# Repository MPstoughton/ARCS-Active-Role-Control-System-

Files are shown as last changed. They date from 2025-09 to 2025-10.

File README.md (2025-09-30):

# ARCS-Active-Rocket-Control-System-

Precision in flight stability is a fundamental requirement for high-powered rocketry, directly influencing both mission safety and performance outcomes. Roll instability, in particular, can degrade aerodynamic efficiency, increase structural loading, and induce trajectory dispersions that compromise recovery reliability and payload success. Slender body rockets can be more inclined to experience unpredicted trajectories due to high roll rates. 

In the context of university and amateur rocketry programs, including the Intercollegiate Rocket Engineering Competition (IREC), NASA Student Launch Initiative (SLI), and the Friends of Amateur Rocketry OUT (FAR-OUT) competition, teams must address stability challenges while operating under strict limitations of weight, cost, and manufacturability. Competition-class rockets typically have masses between 20-40 kg, operate with peak dynamic pressures of 8–15 kPa, and are constrained to commercially available manufacturing processes. Within these regimes, any solution for roll stabilization must provide sufficient control authority while adding less than 1–2 percent to system mass and maintaining costs below approximately $500.

Conventional passive stabilization techniques, such as canted fins, generate roll torque through induced aerodynamic asymmetry but result in drag penalties that reduce apogee depending on Mach number and cant angle. Advanced active approaches, including thrust vector control, cold-gas thrusters, and reaction wheels, offer greater precision but impose significant penalties in mass, power, and cost. Consequently, there remains a clear technical gap for a lightweight, modular, and reliable roll control system tailored to the needs of competition-class rocketry.

The Active Rocket Control System (ARCS) project is conceived to address this gap by introducing an aerodynamic fin-based actuation mechanism capable of dynamically correcting roll during supersonic flight. The system integrates aerodynamic control surfaces with embedded actuation and onboard sensing, enabling closed-loop control of roll rates while minimizing drag penalties. The design emphasizes modularity, allowing integration into existing vehicles with minimal airframe modification, while maintaining manufacturability with student-accessible processes. Beyond roll control, the framework can be expanded to multi-axis stabilization, thereby serving as an enabling technology for advanced trajectory shaping, payload protection, and recovery optimization in future university-level aerospace programs.

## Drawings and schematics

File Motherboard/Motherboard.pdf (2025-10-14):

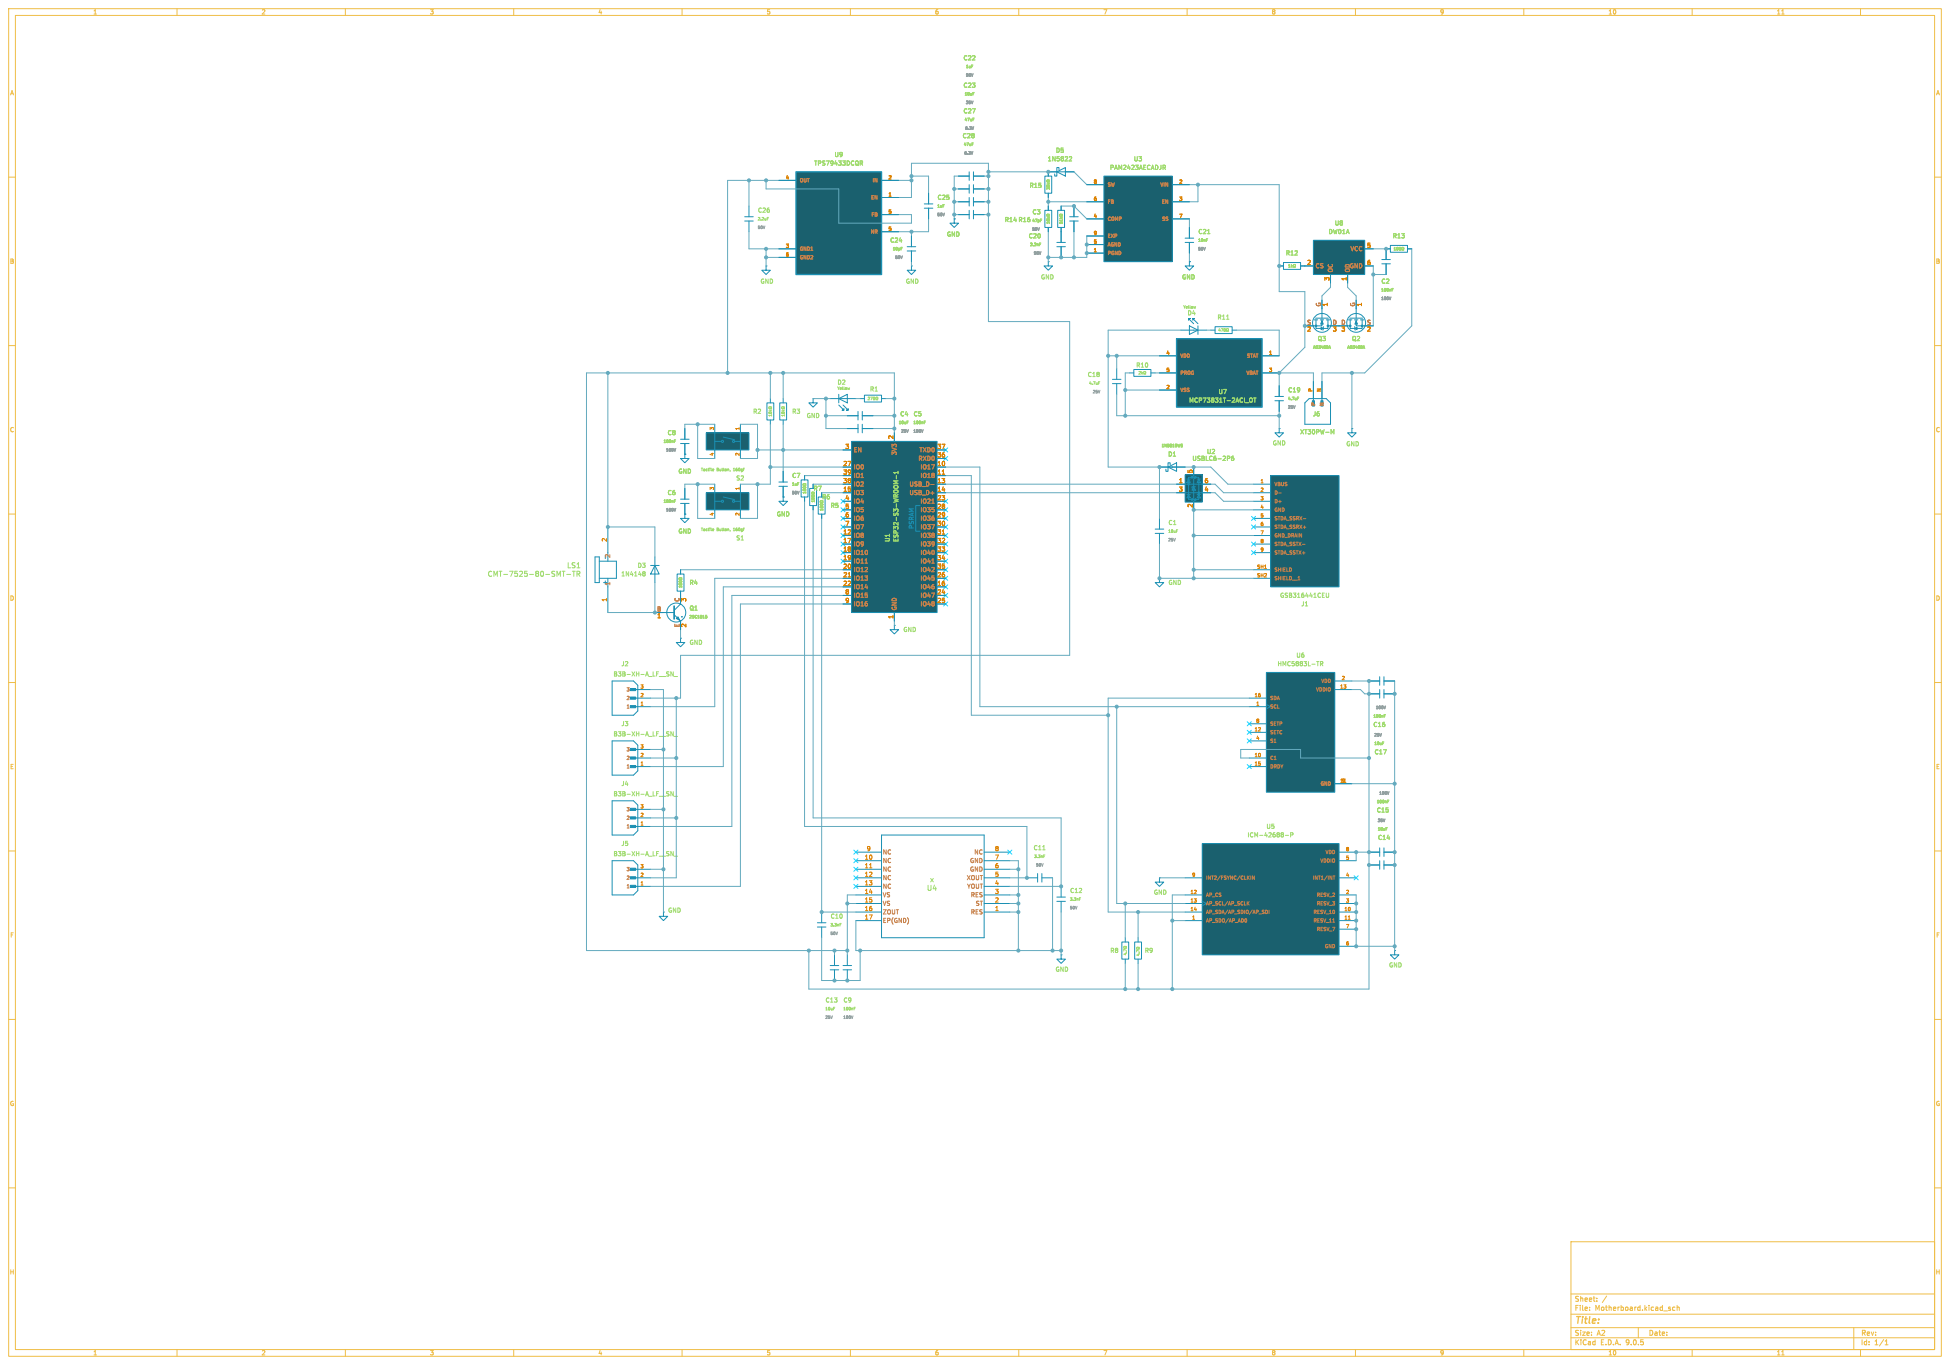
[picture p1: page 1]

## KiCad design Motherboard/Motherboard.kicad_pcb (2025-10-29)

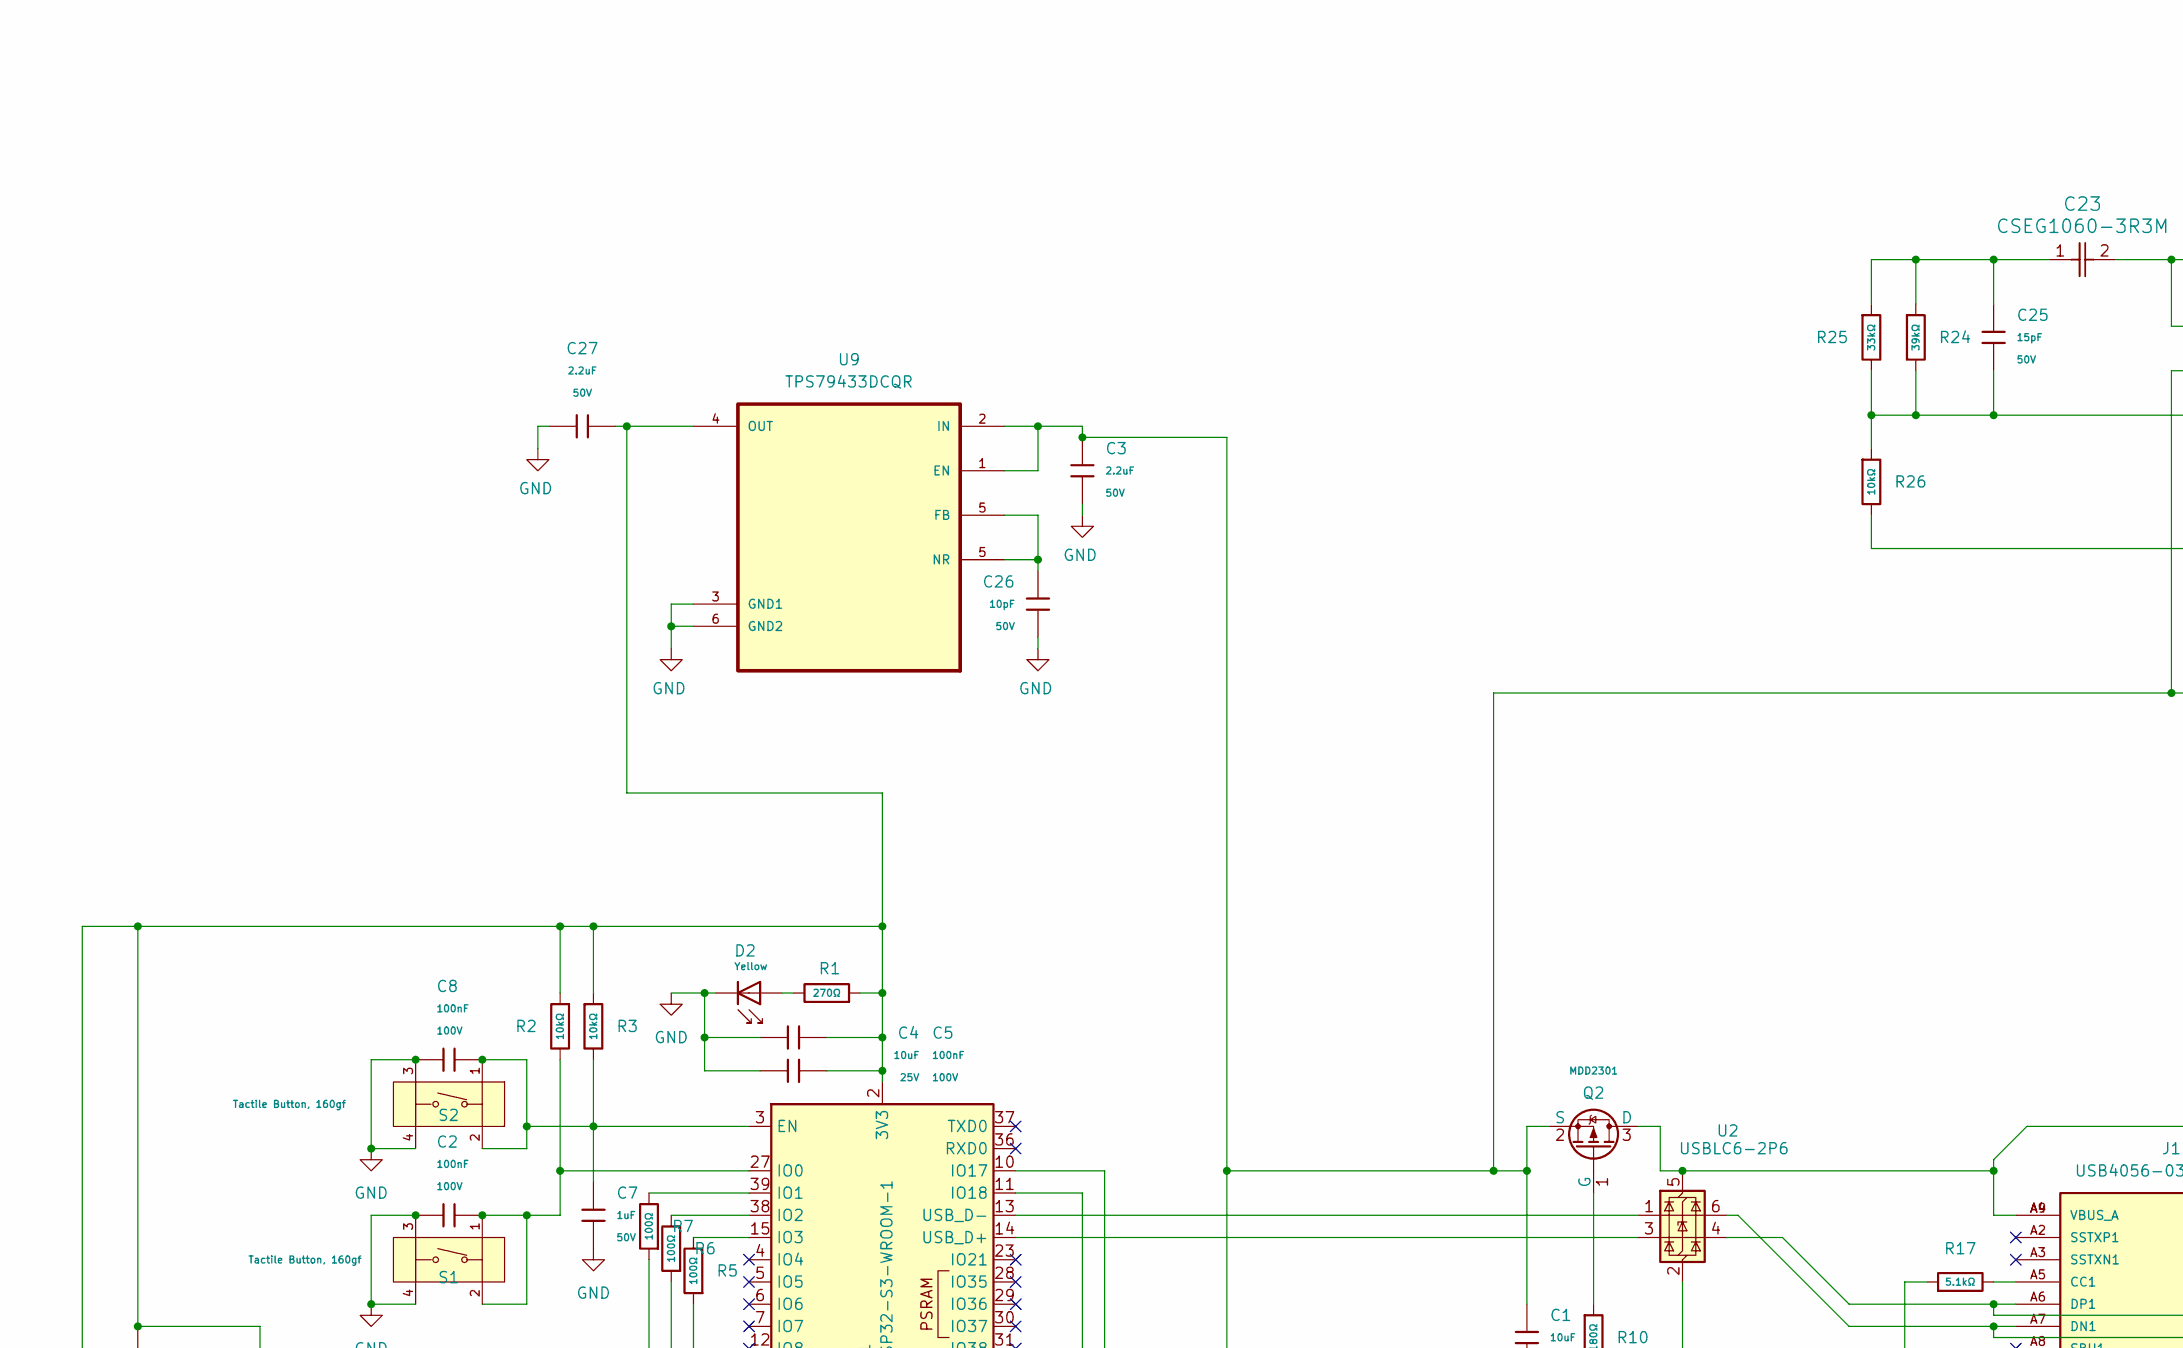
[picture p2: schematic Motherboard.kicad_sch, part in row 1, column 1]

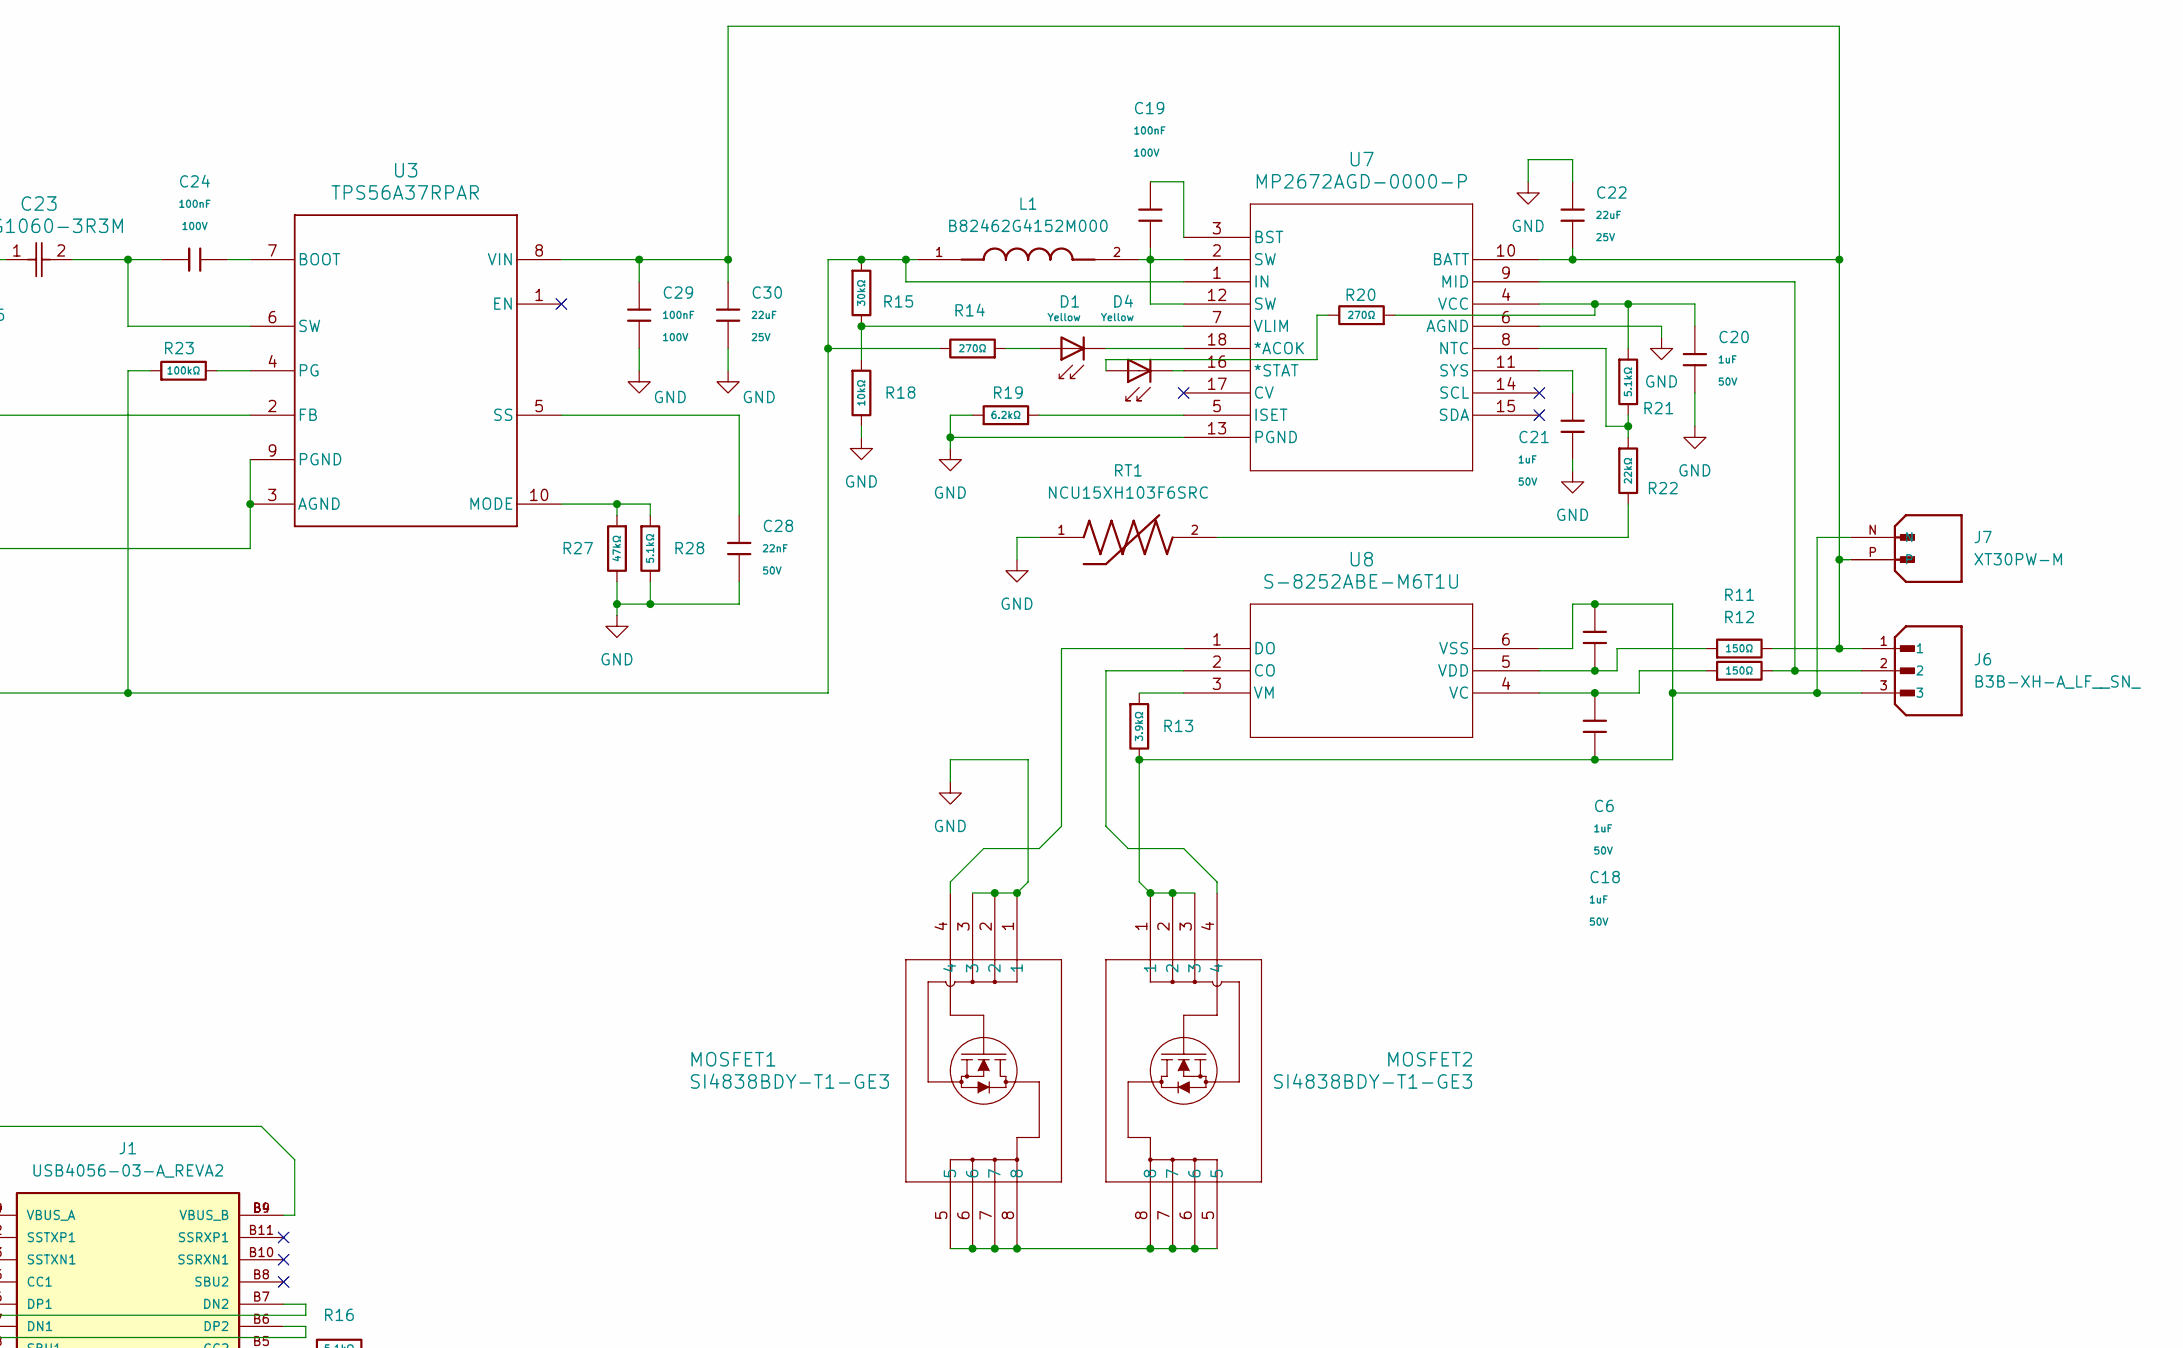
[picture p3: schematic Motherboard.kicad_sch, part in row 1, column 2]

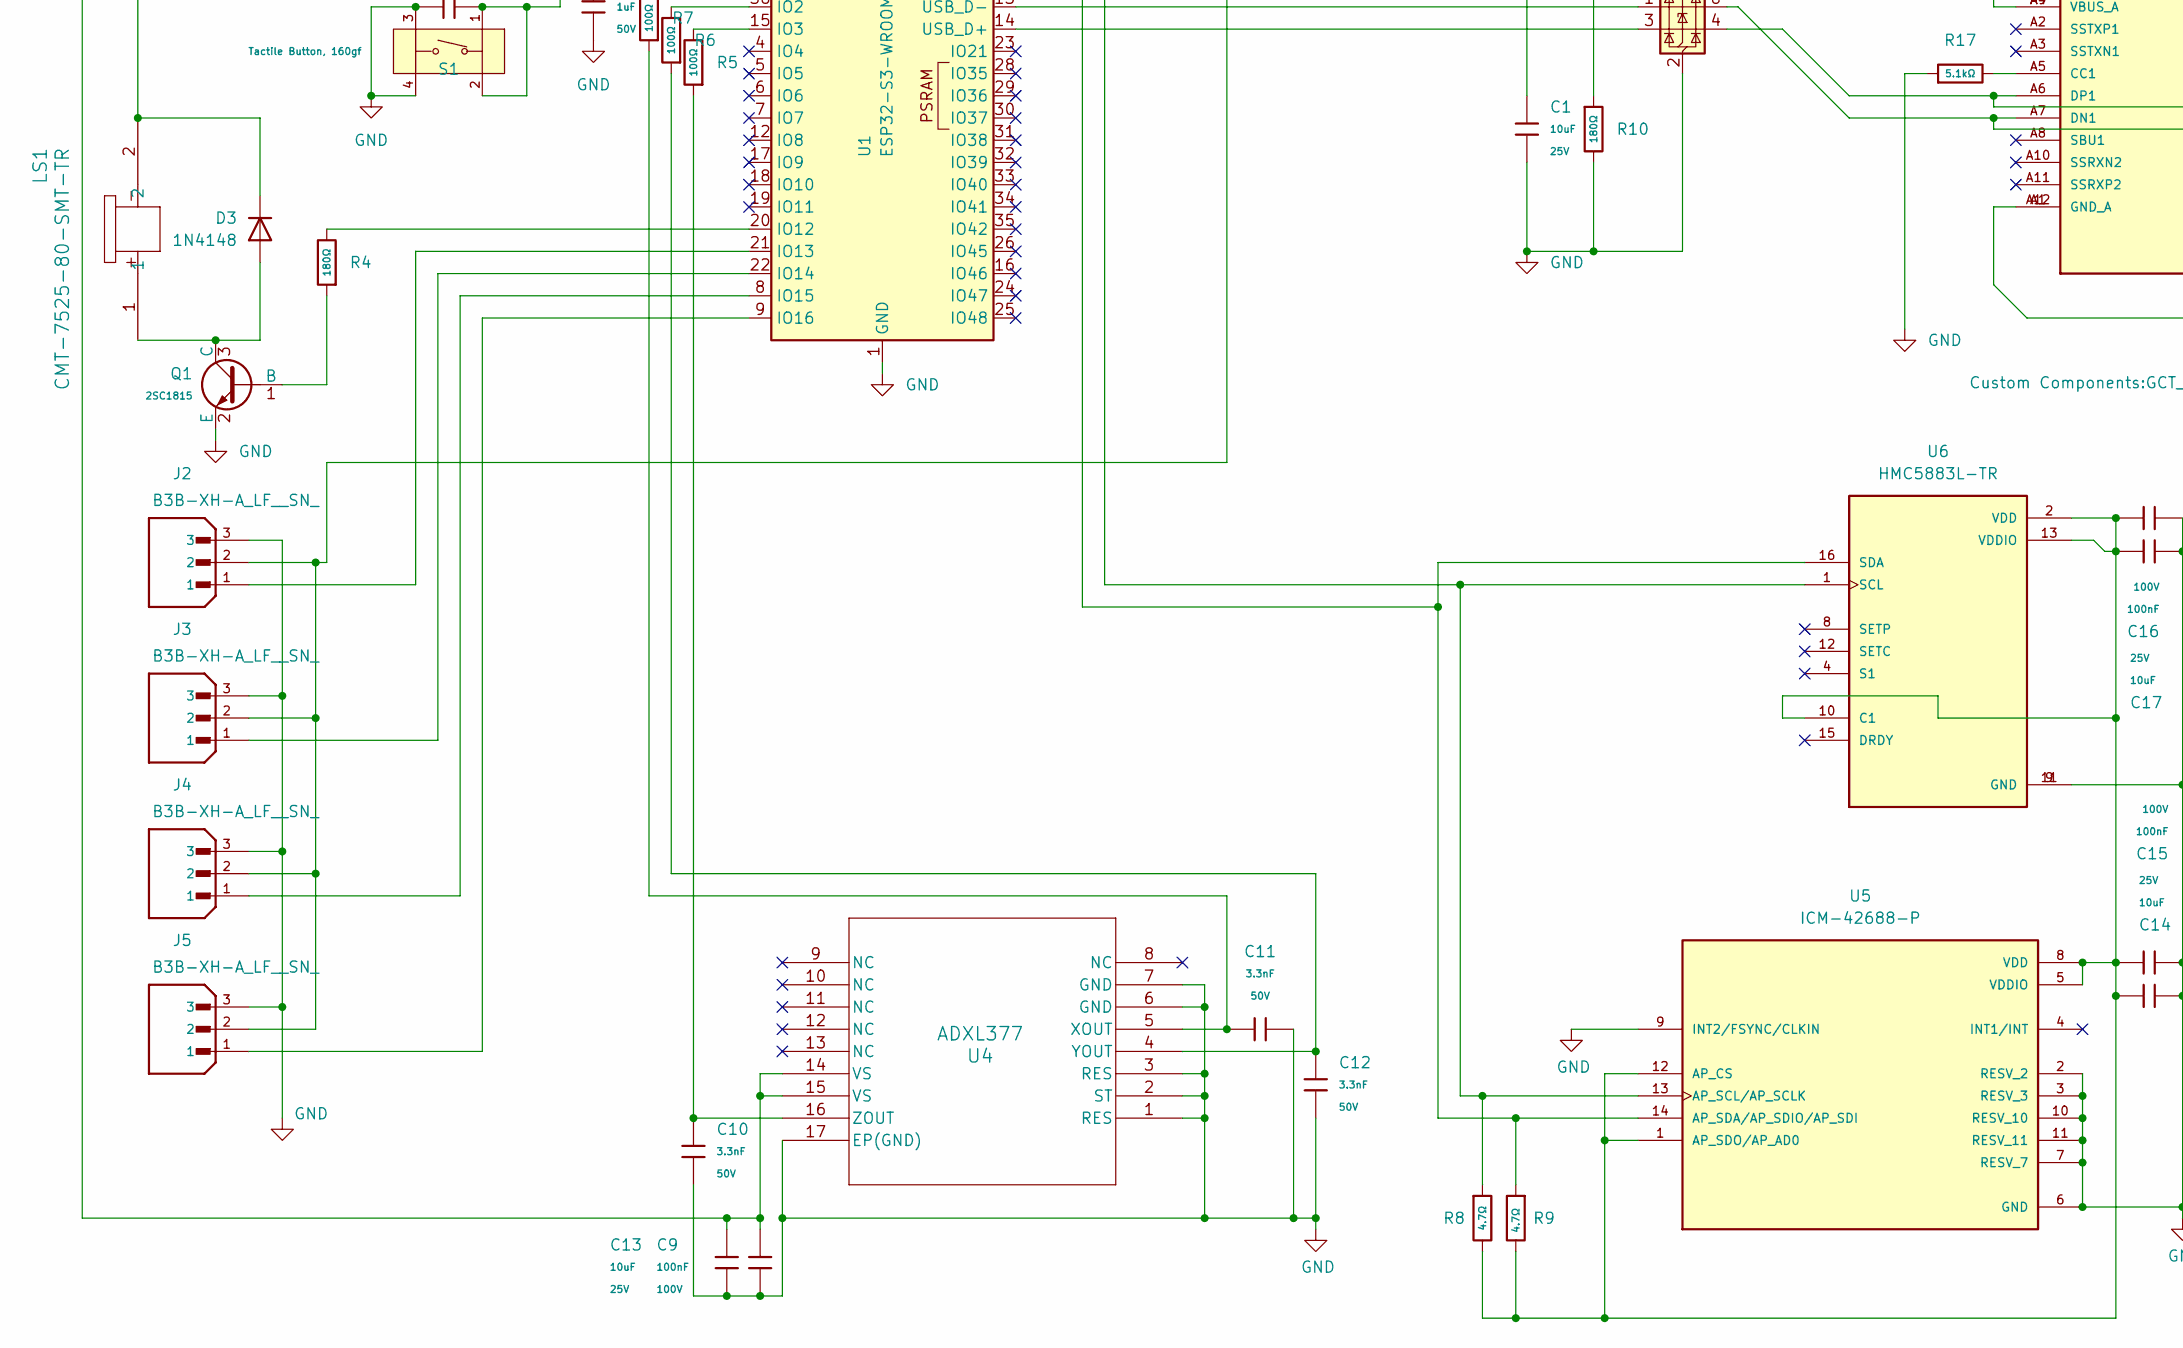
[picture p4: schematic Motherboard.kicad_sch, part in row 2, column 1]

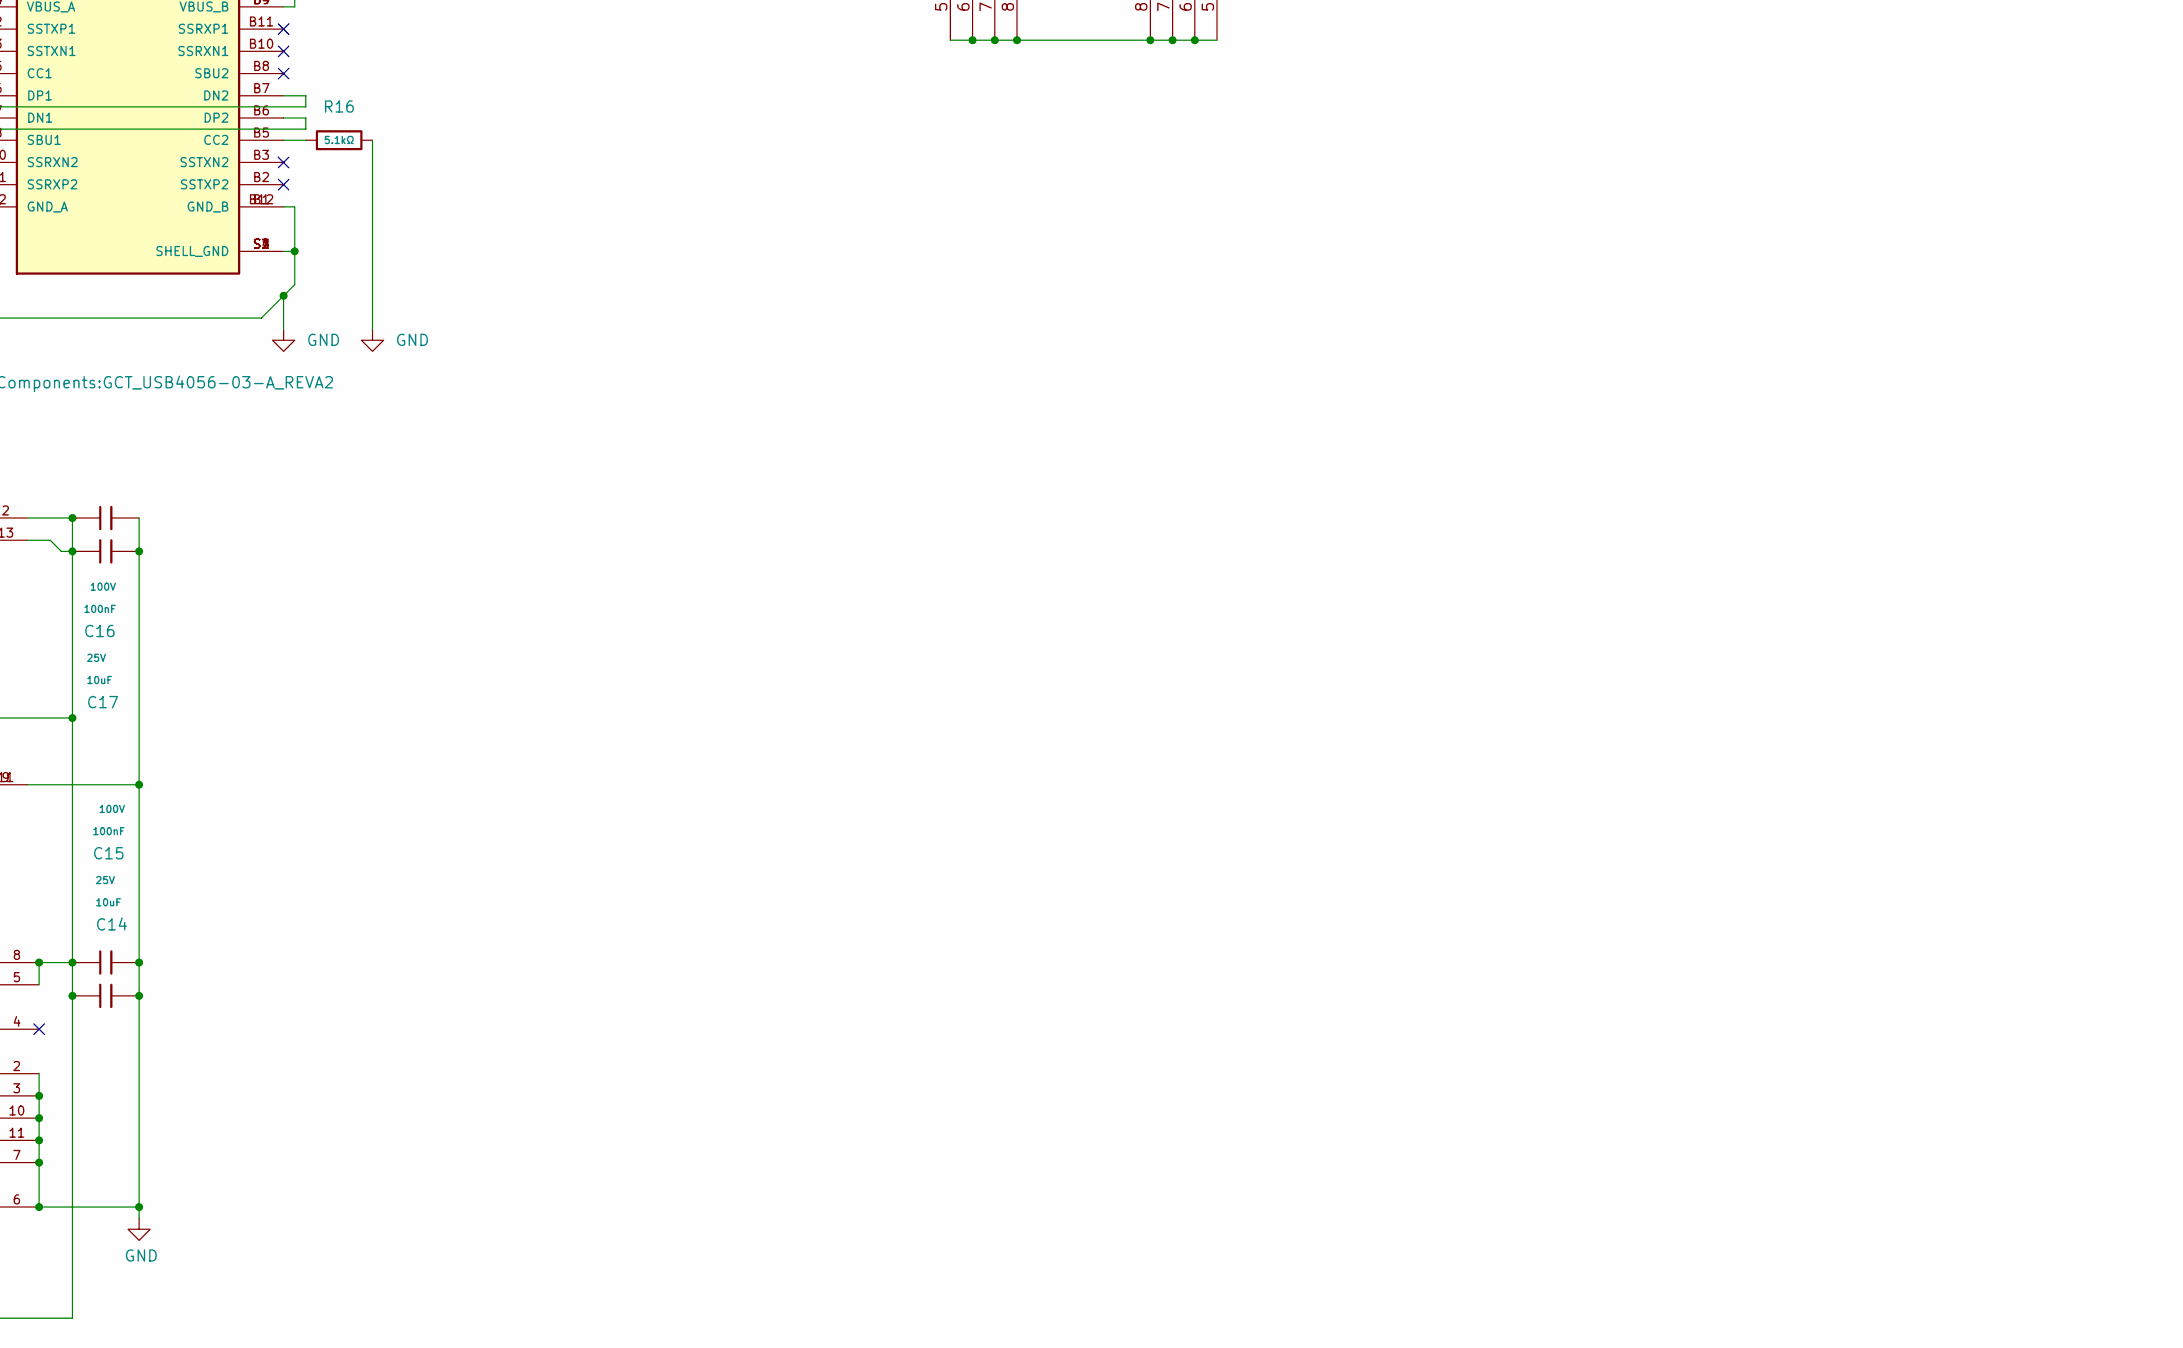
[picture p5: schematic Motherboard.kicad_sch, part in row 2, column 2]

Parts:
C1, C4, C13, C14, C17: 10uF; C_0805; Voltage Rated 25V; Tolerance ±10%; Part CL21A106KAYNNNE; LCSC C15850
C2, C5, C8, C9, C15, C16, C19, C24, C29: 100nF; C_0805; Voltage Rated 100V; Tolerance ±10%; Part CL21B104KCFNNNE; LCSC C28233
C3, C27: 2.2uF; C_0805; Voltage Rated 50V; Tolerance ±10%; Part CL21A225KBQNNNE; LCSC C377773
C6, C7, C18, C20, C21: 1uF; C_0805; Voltage Rated 50V; Tolerance ±10%; Part CL21B105KBFNNNE; LCSC C28323
C10, C11, C12: 3.3nF; C_0603; Voltage Rated 50V; Tolerance ±10%; Part CL10B332KB8NNNC; LCSC C1613
C22, C30: 22uF; C_0805; Voltage Rated 25V; Tolerance ±20%; Part CL21A226MAQNNNE; LCSC C45783
C23: CSEG1060-3R3M; CAP_CSEG1060-3R3M_COD
C25: 15pF; C_0805; Voltage Rated 50V; Tolerance ±5%; Part CC0805JRNPO9BN150; LCSC C107110
C26: 10pF; C_0603; Voltage Rated 50V; Tolerance ±5%; Part CL10C100JB8NNNC; LCSC C1634
C28: 22nF; C_0805; Voltage Rated 50V; Tolerance ±10%; Part CL21B223KBANNNC; LCSC C1729
D1, D2, D4: Yellow; D_0805; Part KT-0805Y; LCSC C2296
D3: 1N4148; D_DO-35_SOD27_P7.62mm_Horizontal
J1: USB4056-03-A_REVA2; GCT_USB4056-03-A_REVA2; PARTREV A2; DigiKey_Part_Number 2073-USB4056-03-ACT-ND
J2, J3, J4, J5, J6: B3B-XH-A_LF__SN_; JST_B3B-XH-A_LF__SN_; PARTREV 7/4/21
J7: XT30PW-M; AMASS_XT30PW-M; PARTREV 1.2
L1: B82462G4152M000; IND_B82462G4152M000; PARTREV 2018-10
LS1: CMT-7525-80-SMT-TR; CMT-7525-80-SMT-TR_CUD
MOSFET1, MOSFET2: SI4838BDY-T1-GE3; SOIC8_NARROW_VIS
Q1: 2SC1815; Q_SOT-23; Part 2SC1815; LCSC C20069143
Q2: MDD2301; Q_SOT-23; Part MDD2301; LCSC C427391
R1, R14, R20: 270Ω; R_0805; Overload Voltage (Max) 150V; Tolerance ±1%; Part 0805W8F2700T5E; LCSC C17590
R2, R3, R26: 10kΩ; R_0805; Overload Voltage (Max) 150V; Tolerance ±1%; Part 0805W8F1002T5E; LCSC C17414
R4, R10: 180Ω; R_0805; Overload Voltage (Max) 150V; Tolerance ±1%; Part 0805W8F1800T5E; LCSC C25270
R5, R6, R7: 100Ω; R_0603; Overload Voltage (Max) 75V; Tolerance ±1%; Part 0603WAF1000T5E; LCSC C22775
R8, R9: 4.7Ω; R_0805; Overload Voltage (Max) 150V; Tolerance ±1%; Part 0805W8F470KT5E; LCSC C17675
R11, R12: 150Ω; R_0805; Overload Voltage (Max) 150V; Tolerance ±1%; Part 0805W8F1500T5E; LCSC C17471
R13: 3.9kΩ; R_0805; Overload Voltage (Max) 150V; Tolerance ±1%; Part 0805W8F3901T5E; LCSC C17614
R15: 30kΩ; R_0805; Overload Voltage (Max) 150V; Tolerance ±1%; Part 0805W8F3002T5E; LCSC C17621
R16, R17, R21, R28: 5.1kΩ; R_0805; Overload Voltage (Max) 150V; Tolerance ±1%; Part 0805W8F5101T5E; LCSC C27834
R18: 10kΩ; R_0603; Overload Voltage (Max) 75V; Tolerance ±1%; Part 0603WAF1002T5E; LCSC C25804
R19: 6.2kΩ; R_0805; Overload Voltage (Max) 150V; Tolerance ±1%; Part 0805W8F6201T5E; LCSC C17767
R22: 22kΩ; R_0805; Overload Voltage (Max) 150V; Tolerance ±1%; Part 0805W8F2202T5E; LCSC C17560
R23: 100kΩ; R_0805; Overload Voltage (Max) 150V; Tolerance ±1%; Part 0805W8F1003T5E; LCSC C149504
R24: 39kΩ; R_0805; Overload Voltage (Max) 150V; Tolerance ±1%; Part 0805W8F3902T5E; LCSC C25826
R25: 33kΩ; R_0805; Overload Voltage (Max) 150V; Tolerance ±1%; Part 0805W8F3302T5E; LCSC C17633
R27: 47kΩ; R_0805; Overload Voltage (Max) 150V; Tolerance ±1%; Part 0805W8F4702T5E; LCSC C17713
RT1: NCU15XH103F6SRC; THRMC1005X55N
S1, S2: Tactile Button, 160gf; SW-SMD_4P-L5.1-W5.1-P3.70-LS6.5-TL-2; Voltage Rating (Dc) 12V; Part TS-1187A-B-A-B; LCSC C318884
U1: ESP32-S3-WROOM-1
U2: USBLC6-2P6; SOT-666
U3: TPS56A37RPAR; RPA0010A-MFG
U4: ADXL377; CP_16_28_ADI
U5: ICM-42688-P; PQFN50P300X250X97-14N; PARTREV 1.2
U6: HMC5883L-TR; XDCR_HMC5883L-TR; PARTREV E
U7: MP2672AGD-0000-P; QFN-18_MP2672A_MNP
U8: S-8252ABE-M6T1U; SOT236-A-PKG_MP006-A-P-SD-2.1_ABL
U9: TPS79433DCQR; SOT127P706X180-6N; DigiKey_Part_Number 296-14437-1-ND

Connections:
GND: C1.2, C2.2, C3.1, C4.2, C5.2, C7.2, C8.2, C9.2, C10.1, C11.2, C12.1, C13.1, C14.1, C15.2, C16.2, C17.1, C20.2, C21.2, C22.1, C26.2, C27.1, C28.2, C29.2, C30.2, D2.1, J1.A1 (GND_A), J1.A12 (GND_A), J1.B1 (GND_B), J1.B12 (GND_B), J1.S1 (SHELL_GND), J1.S2 (SHELL_GND), J1.S3 (SHELL_GND), J1.S4 (SHELL_GND), J2.3, J3.3, J4.3, J5.3, MOSFET1.1, MOSFET1.2, MOSFET1.3, Q1.2 (E), R10.2, R16.2, R17.1, R18.2, R19.1, R27.2, R28.2, RT1.1, S1.3 (C), S1.4 (D), S2.3 (C), S2.4 (D), U1.1 (GND), U1.40 (GND), U1.41 (GND), U2.2 (GND), U4.1 (RES), U4.2 (ST), U4.3 (RES), U4.6 (GND), U4.7 (GND), U4.17 (EP(GND)), U5.2 (RESV_2), U5.3 (RESV_3), U5.6 (GND), U5.7 (RESV_7), U5.9 (INT2/FSYNC/CLKIN), U5.10 (RESV_10), U5.11 (RESV_11), U6.9 (GND), U6.11 (GND), U7.6 (AGND), U7.13 (PGND), U9.3 (GND1), U9.6 (GND2)
unnamed: C19.2, L1.2, U7.2 (SW), U7.12 (SW)
unnamed: C23.1, C25.1, R24.1, R25.1
unnamed: D1.2, R14.1
unnamed: D2.2, R1.2
unnamed: D3.2 (A), LS1.1, Q1.3 (C)
unnamed: C4.1, C5.1, C9.1, C13.2, C27.2, D3.1 (K), LS1.2, R1.1, R2.1, R3.1, U1.2 (3V3), U4.14 (VS), U4.15 (VS), U9.4 (OUT)
unnamed: D4.2, R20.2
unnamed: J1.A5 (CC1), R17.2
unnamed: J1.B5 (CC2), R16.1
unnamed: J1.A7 (DN1), J1.B6 (DP2), U2.6 (I/O1)
unnamed: J1.A6 (DP1), J1.B7 (DN2), U2.4 (I/O2)
unnamed: MOSFET1.5, MOSFET1.6, MOSFET1.7, MOSFET1.8, MOSFET2.5, MOSFET2.6, MOSFET2.7, MOSFET2.8
unnamed: Q1.1 (B), R4.1
unnamed: J1.A4 (VBUS_A), J1.A9 (VBUS_A), J1.B4 (VBUS_B), J1.B9 (VBUS_B), Q2.3 (D), U2.5 (VBUS)
unnamed: Q2.1 (G), R10.1
unnamed: C1.1, C3.2, J2.2, J3.2, J4.2, J5.2, L1.1, Q2.2 (S), R14.2, R15.1, R23.1, U7.1 (IN), U9.1 (EN), U9.2 (IN)
unnamed: R22.2, RT1.2
unnamed: C2.1, R2.2, S1.1 (A), S1.2 (B), U1.27 (IO0)
unnamed: C7.1, C8.1, R3.2, S2.1 (A), S2.2 (B), U1.3 (EN)
unnamed: R7.2, U1.39 (IO1)
unnamed: R6.2, U1.38 (IO2)
unnamed: R5.2, U1.15 (IO3)
unnamed: R4.2, U1.20 (IO12)
unnamed: J2.1, U1.21 (IO13)
unnamed: J3.1, U1.22 (IO14)
unnamed: J4.1, U1.8 (IO15)
unnamed: J5.1, U1.9 (IO16)
unnamed: R8.1, U1.10 (IO17), U5.13 (AP_SCL/AP_SCLK), U6.1 (SCL)
unnamed: R9.1, U1.11 (IO18), U5.14 (AP_SDA/AP_SDIO/AP_SDI), U6.16 (SDA)
unnamed: U1.14 (USB_D+), U2.3 (I/O2)
unnamed: U1.13 (USB_D-), U2.1 (I/O1)
unnamed: R26.2, U3.3 (AGND), U3.9 (PGND)
unnamed: C24.2, U3.7 (BOOT)
unnamed: C25.2, R24.2, R25.2, R26.1, U3.2 (FB)
unnamed: R27.1, R28.1, U3.10 (MODE)
unnamed: R23.2, U3.4 (PG)
unnamed: C28.1, U3.5 (SS)
unnamed: C23.2, C24.1, U3.6 (SW)
unnamed: C22.2, C29.1, C30.1, J6.1, J7.P, R11.2, U3.8 (VIN), U7.10 (BATT)
unnamed: C11.1, R7.1, U4.5 (XOUT)
unnamed: C12.2, R6.1, U4.4 (YOUT)
unnamed: C10.2, R5.1, U4.16 (ZOUT)
unnamed: C14.2, C15.1, C16.1, C17.2, R8.2, R9.2, U5.1 (AP_SDO/AP_AD0), U5.5 (VDDIO), U5.8 (VDD), U5.12 (AP_CS), U6.2 (VDD), U6.10 (C1), U6.13 (VDDIO)
unnamed: D1.1, U7.18 (*ACOK)
unnamed: D4.1, U7.16 (*STAT)
unnamed: C19.1, U7.3 (BST)
unnamed: R19.2, U7.5 (ISET)
unnamed: J6.2, R12.2, U7.9 (MID)
unnamed: R21.2, R22.1, U7.8 (NTC)
unnamed: C21.1, U7.11 (SYS)
unnamed: C20.1, R20.1, R21.1, U7.4 (VCC)
unnamed: R15.2, R18.1, U7.7 (VLIM)
unnamed: MOSFET2.4, U8.2 (CO)
unnamed: MOSFET1.4, U8.1 (DO)
unnamed: C18.1, R12.1, U8.4 (VC)
unnamed: C6.2, R11.1, U8.5 (VDD)
unnamed: R13.1, U8.3 (VM)
unnamed: C6.1, C18.2, J6.3, J7.N, MOSFET2.1, MOSFET2.2, MOSFET2.3, R13.2, U8.6 (VSS)
unnamed: C26.1, U9.5 (FB)

Board: 2 copper layers, 82 parts (0 on the bottom side), 59 nets, no tracks yet.

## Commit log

2025-10-07 adds a KiCAD project! :D
    [Motherboard.kicad_pcb, Motherboard.kicad_sch]
2025-10-08 does like everything
    [Motherboard.kicad_sch]
2025-10-14 adds bms system
    [Motherboard.kicad_sch]
2025-10-29 added bms system + buck converter
    [Motherboard.kicad_pcb, Motherboard.kicad_sch]
